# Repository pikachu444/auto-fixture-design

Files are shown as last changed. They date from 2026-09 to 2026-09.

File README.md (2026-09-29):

# Auto Fixture Design



시편 치수·물성, 시험기 구성, 프린터 출력 범위를 입력하면 **계산 → 제약 검사 → 실제 CAD 생성 → 파일 재검증 → 보고서**를 실행합니다. CadQuery/OpenCascade의 솔리드 모델을 STEP/STL/3MF로 출력합니다.

## 실행 결과 받기

1. [Actions](https://github.com/pikachu444/auto-fixture-design/actions/workflows/fixture-ci.yml)에서 최신 완료 실행을 엽니다.
2. **Artifacts → fixture-results-커밋SHA**를 다운로드합니다.
3. 압축을 풀고 **`suite/DESIGN_VERIFICATION.pdf`**를 열면 요구조건·계산·CAD 증거·차단 사례·수계산/해석·미검증 범위를 정리한 설계 검증 보고서를 볼 수 있습니다. `suite/REPORT.pdf`는 간단한 실행 요약입니다. `suite/index.html`에는 사례별 상세 보고서가 있고, 각 사례 폴더에는 CAD, HTML/Markdown 보고서, JSON, BOM이 있습니다.

`main`에 코드를 올리거나 PR을 만들 때 자동 실행하며 **Run workflow**로 수동 실행할 수도 있습니다. 저장 기간은 30일입니다. CI 성공은 계산·소프트웨어 회귀 검사 성공이며, 실물 제작 승인이 아닙니다.

## CAD 형상에서 치수를 선택해 파라미터 정의

화면의 **CAD 치수 정의** 탭은 편집 가능한 FreeCAD `.FCStd` 문서를 엽니다. 처음에는 사용자 파라미터가 없습니다. 실제 최종 솔리드를 마우스로 회전·확대하고 **면을 클릭**하면 기존 CAD 치수 중 해당 면이 변경되는 후보를 보여 줍니다. 후보 또는 전체 피처 트리에서 길이·반경이나 Sketcher 구동 치수를 선택하고 **이름과 허용 범위를 직접 지정**하면 그 정의가 `.FCStd` 원본에 저장됩니다. 이어서 정의한 값만 변경하고 원본을 재계산해 STEP/STL/3MF와 판정 보고서를 받습니다. 작성된 `.FCStd`를 다시 열어도 정의가 남습니다.

샘플 롤러 지지대에서는 `SupportBlock.Length`를 사용자가 `my_support_width`로 정의하여 폭 32→38 mm를 재생성합니다. 이어 `RollerCradle.Radius`와 `BoltBore1.Radius`를 선택할 수 있으며, 구멍 반경으로 외곽 여유가 2 mm 미만이 되면 CAD 출력을 차단합니다. 이 이름은 샘플 실행에서 사용자가 붙인 예시일 뿐, 화면에 고정된 입력 목록이 아닙니다. CI는 정의·재생성·원본 다시 열기·차단을 실제 FreeCAD로 실행합니다.

별도 **Sketcher 치수 예제**에서는 원형 스케치의 구동 반경을 선택해 `my_locator_radius`로 정의하고 4→6 mm로 변경한 출력물의 외경 12 mm를 확인합니다. 최종 형상에 영향을 주지 않는 피처 치수를 선택하면 등록을 거부합니다.

신뢰하는 `.FCStd` 문서를 직접 가져와 피처/스케치 치수를 정의할 수도 있습니다. 최종 출력할 솔리드가 표시되지 않으면 형상 트리에서 지정해야 합니다. 면을 클릭한 후보는 각 치수를 조금 변경해 FreeCAD를 재계산하고 해당 면의 변화 여부를 비교한 **제안**이므로 사용자가 설계 의도를 확인해야 합니다. 형상 면의 개수·순서가 바뀌는 변경에서는 후보를 제안하지 않습니다. 복잡한 문서(256면·64치수·5만 삼각형 초과)는 3D 선택을 생략하고 원래의 치수 트리를 사용합니다. FreeCAD GUI에서 새 Sketcher 구속을 추가한 후 저장한 문서를 가져오면 그 구동 치수가 후보가 됩니다. **피처 이력이 없는 STEP의 임의 면에서 구동 치수를 자동 복원하는 기능은 아닙니다.** 출력 강도·장비 장착은 별도 검증입니다.

로컬 실행에는 FreeCADCmd 1.1 계열을 설치하고 실행 파일 경로를 `FREECAD_CMD` 환경변수에 지정해야 합니다. Linux용 CI는 FreeCAD 1.1.4 AppImage를 SHA-256 확인 후 실행합니다. 이전 **소스 변수 변경** 탭은 CadQuery 파일에 미리 선언된 변수를 변경하는 기존 경로로 남겨 두었습니다.

## 구현한 사례

| 유형 | 실제 생성하는 부품 | 계산·검출 항목 |
|---|---|---|
| 3점 굽힘 | 슬롯 베이스·지지대, 금속 롤러 포함 조립체 | 4→8 mm 시편 변경, 간격 64→128 mm, 베이스 선택, 예상 하중·변위, 로드셀·공구·프린터 초과 |
| 필름 인장 | 시편 폭에 맞춘 벤치 정렬 트레이 | 물림 길이, 그립 폭, 예상 하중, 연신에 필요한 이동량 |
| 폼 압축 | 양 대각선의 탈착식 L자 위치 결정구 | 목표 압축률의 입력 응력 기반 하중, 압축판 범위, 가용 이동량 |
| 정적 굽힘 반경 | 반원형 반경 확인구 | 표면 변형률·최소 반경, 출력 크기 |

11개 시나리오: CAD 생성 후보 5개, 의도한 제약 위반 6개. 입력은 가상의 엔지니어링 사례이며 제조사 실험 데이터로 주장하지 않습니다. 설계 근거와 실제 사용 조건은 [ENGINEERING.md](docs/ENGINEERING.md)를 참고하세요.

### CAD 소스가 소유하는 파라미터

기존 11개 실험 규칙과 별도로 **CAD 모델 파라미터** 화면이 있습니다. `models/roller_support.py`, `models/film_tray.py`의 숫자 선언이 형상 치수의 원본이며 `FIXTURE_META`가 항목명·단위·허용 범위를 정의합니다. 프로그램은 CadQuery CQGI로 모델별 선언을 자동 발견해 입력 폼을 만들고, 바꾼 값으로 같은 CAD 소스를 다시 실행합니다. 모델 파일에 적힌 구멍 여유 등의 관계식이 실패하면 CAD를 내보내지 않습니다. 새로운 신뢰 가능한 CadQuery 모델을 `models/`에 추가하면 일반 실행 경로를 재사용하며 서버/화면에 그 형상을 하드코딩할 필요가 없습니다.

예를 들어 롤러 지지대의 `support_width_mm`를 32→38 mm로 바꾸면 재생성한 STEP의 폭도 38 mm가 됩니다. 독립 모델인 필름 트레이의 `specimen_width_mm`를 15→20 mm로 바꾸면 외곽 폭은 27.5→32.5 mm입니다. CI는 두 변형과 모델 내 관계식에 의한 거부를 `artifacts/models/`에 기록합니다.

**입력은 신뢰할 수 있는 로컬 Python CAD 파일로 제한합니다.** 임의 파일 업로드와 기존 STEP 파일의 파라미터 자동 복원은 제공하지 않습니다. STEP/STL/3MF는 내보내기 형상이며, 재편집 가능한 원본은 `.py` CAD 소스입니다. 이 두 신규 모델의 구조해석과 실제 장비 적합성은 아직 검증하지 않았습니다.

새 형상을 등록하려면 `models/새이름.py`에 `FIXTURE_META`와 파일 최상위의 숫자 할당을 같은 이름으로 작성하고, 그 숫자를 형상 작성 코드에 사용한 뒤 최종 출력 부품 하나를 `show_object(...)`로 지정합니다. 예를 들어 `body_width_mm = 12.0`과 메타데이터의 `body_width_mm` 항목을 선언하고 `cq.Workplane("XY").box(body_width_mm, 9, 7)`을 출력하면 화면에서 폭을 바꿀 수 있습니다. 파일을 저장하고 화면을 새로고침하면 모델 목록에 나타납니다. 이 경로는 신뢰할 수 있는 Python 코드만 실행하며 현재 단일 출력 솔리드와 mm 단위의 숫자 입력을 지원합니다. 새 모델의 물리적 검사 기준은 해당 CAD 소스의 관계식과 별도 엔지니어링 검토로 정의해야 합니다.

**현재 제작 승인 상태는 모두 UNKNOWN입니다.** 인장·압축 출력 보조구는 하중 시험 전에 제거합니다. 굽힘 지그의 출력물 강도·체결부·장비 어댑터는 검증 전입니다. 반경 확인구는 반복 폴딩 시험기가 아니며 피로수명을 예측하지 않습니다. 장비를 제어하지 않습니다.

### 구조해석 예비 검토

CI는 생성한 굽힘 지그의 **출력 지지대 STEP**을 Gmsh로 형상 경계에 맞춘 10절점 사면체 메시로 만들고 CalculiX에서 정적 선형 탄성 해석을 실행합니다. 작은 볼트 구멍 주변의 뒤집힌 곡면 요소를 피하려고 2차 절점은 직선 보간합니다. 따라서 곡면은 삼각형 면으로 근사되며 메시 세분화 검사가 필요합니다. 최대 요소 크기를 4→3→2 mm로 줄여 접촉부 수직 변위의 메시 민감도를 기록하며, 실제 FRD 응력장을 읽어 최대 평균 절점 von Mises 응력도 **진단값**으로 기록합니다. 원본 STEP·메시·해석 입력·FRD 결과와 `suite/structural_screen/result.json`을 보관합니다. 별도의 상용 라이선스는 필요 없습니다.

로컬에서도 Gmsh와 CalculiX `ccx`를 설치한 다음 실행할 수 있습니다.

```bash
python -m scripts.run_structural_screen --input examples/bend_8mm.json --material examples/printed_material_ASSUMED.json --output artifacts/structural-001
```

**이 결과로 지그 강도 합격 여부를 판정하지 않습니다.** 예제의 출력 방향별 탄성계수·전단계수는 측정값이 아닌 가정입니다. 입력 모델은 등방성 또는 직교이방성을 지원하며 CAD X/Y/Z와 출력 적층 방향의 대응을 명시해야 합니다. 지지대 바닥을 완전 고정하고 두 지지대가 설계 하중을 절반씩 받는다고 놓았습니다. 실제 베이스·체결부·비선형 롤러 접촉 및 출력 방향별 강도는 모델링하지 않았습니다. 지지대만 해석했으므로 전체 조립체 FEA나 출력물 실험을 대신하지 않습니다.

모든 사례 보고서에는 해당 시편의 하중·이동량·변형률에 대한 **병행 산술 대조**를 담습니다. 굽힘 해석 결과에는 지지대 총단면의 평균 압축응력 및 균일 축압축 변위도 FEA 접촉점 변위와 나란히 보여줍니다. 시편 수계산은 동일 이상화 식의 별도 구현 검사이며 실제 실험 검증은 아닙니다. 지지대 규모 비교는 구멍과 국부 접촉을 생략하므로 FEA와 일치해야 한다는 판정 기준으로 쓰지 않습니다.

## 로컬 프로그램 실행

Python 3.12 환경이 필요합니다.

```bash
python -m venv .venv
```

Windows PowerShell:

```powershell
.venv\Scripts\python.exe -m pip install -r requirements.txt
.venv\Scripts\python.exe -m fixturelab serve
```

macOS / Linux:

```bash
.venv/bin/python -m pip install -r requirements.txt
.venv/bin/python -m fixturelab serve
```

브라우저에서 `http://127.0.0.1:8765`를 엽니다. 사례를 선택하고 입력을 수정한 다음 **CAD 생성 및 검증 실행**을 누릅니다. 실제 생성 보고서를 표시하고 ZIP을 다운로드합니다. 로컬 접속만 허용하며 CAD 생성은 시간 제한이 있는 별도 프로세스에서 수행합니다.

화면에는 **기존 실험 예제**와 **CAD 모델 파라미터**가 따로 있습니다. 후자는 CAD 소스에서 항목을 읽어 폼을 만들고 STEP/STL/3MF를 재생성합니다. 형상은 정적 미리보기이며 회전 가능한 3D 편집기와 유한요소해석 실행 버튼은 없습니다. 기존 굽힘 조립체의 예비해석은 위 CLI 명령 또는 GitHub Actions에서 별도로 실행합니다. 자동으로 지그를 최적화하거나 대체 설계를 찾지는 않습니다.

## 명령줄 / 자동화

가상환경을 활성화한 터미널에서:

```bash
python -m fixturelab suite --output artifacts/run-001
python -m fixturelab generate --input examples/bend_8mm.json --output artifacts/custom-001
python -m fixturelab model --model roller_support --parameters examples/roller_width_38.json --output artifacts/model-001
```

결과가 섞이지 않도록 출력 디렉터리는 비어 있어야 합니다. 재실행에는 새 디렉터리 이름을 사용하세요. 단일 사례의 종료 코드: 0=계산 완료·검토 필요, 2=설계 제약 위반, 그 외=계산/입력 오류. suite는 기대 판정과 일치해야 0으로 끝납니다. 거부 사례를 무조건 오류로 취급하지 않습니다.

## 테스트

```bash
python -m pip install -r requirements-dev.txt
python -m pytest --junitxml=artifacts/unit-tests.xml
python -m fixturelab suite --output artifacts/test-suite
python -m playwright install chromium
python scripts/browser_smoke.py
```

설계 검증 PDF는 구조해석 결과까지 필요합니다. Gmsh와 CalculiX를 설치한 환경에서 suite 실행 후 다음을 추가로 실행합니다.

```bash
python -m scripts.run_structural_screen --input examples/bend_8mm.json --material examples/printed_material_ASSUMED.json --output artifacts/test-suite/structural_screen
python scripts/build_ci_report.py --suite artifacts/test-suite --output artifacts/test-suite/REPORT.pdf
python -m scripts.build_design_verification_report --suite artifacts/test-suite --output artifacts/test-suite/DESIGN_VERIFICATION.pdf
```

브라우저 검사는 Chromium에서 시편 폭을 변경하고 실제 CAD를 생성한 뒤 ZIP 내부 치수가 바뀌었는지 확인합니다. 이어서 이동량 부족 사례가 거부되는지 검사합니다. GitHub Actions는 브라우저 실행에 필요한 Linux 시스템 라이브러리도 설치합니다.
CAD 소스 파라미터 화면에서도 롤러 지지대 폭 변경과 관계식 위반 차단을 브라우저에서 검사합니다.

로컬 PDF 생성에는 한국어 TrueType 글꼴이 필요합니다. CI에서는 `fonts-nanum`을 설치해 PDF에 글꼴을 포함합니다. Windows에서는 시스템의 맑은 고딕을 사용합니다.

## 구성

- `fixturelab/`: 계산·파라메트릭 CAD·검증·보고서·로컬 웹 프로그램
- `models/`: 모델 내부에 숫자 파라미터·범위·형상 관계식을 가진 CadQuery 원본
- `examples/`: 편집 가능한 입력 JSON 및 기대 판정 목록
- `tests/`: 독립 보 공식, 경계, 오류 입력, 파일 재읽기 검사
- `.github/workflows/fixture-ci.yml`: 실제 실행·보고서·아티팩트 자동화
- `docs/ENGINEERING.md`: 식, 가정, 근거와 미구현 범위
- `docs/planning/`: 기존 상세 기획과 미실행 제품 인수 검사
- `legacy/`: 앞서 실행했던 첫 굽힘 데모와 당시 결과 보존

의존성 직접 버전을 고정하고 실제 설치된 전체 버전은 CI의 `resolved-environment.txt`에 기록합니다. 결과에는 입력 SHA-256, 실행 시간, 코드 커밋과 라이브러리 버전이 포함됩니다. G-code, 실제 출력, **지지대 외의 전체 조립체 FEA**, 피로시험 및 기존 CAD 파라미터 가져오기는 아직 구현하지 않았습니다.

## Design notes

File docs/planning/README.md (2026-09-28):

# 시험 지그 프로그램 개발 인계 패키지 1.1

## 읽는 순서
1. fixture_plan.md: 장비 선정, 기존 13개 시험 시나리오와 추가 6개 제작 시나리오, CAD·판정·화면·개발 명세.
2. equipment_profiles.json: 제조사 확인값과 미확인 항목. 실제 설치 장비의 인증 데이터가 아닙니다.
3. scenario_inputs.json: 개발용 입력. 실제 소재의 보증 물성이 아닙니다.
4. acceptance_tests.csv: 제품 구현 후 실행할 53개 수용시험. 현재 제품 테스트는 미실행입니다.
5. verify_planning_examples.py와 planning_calculation_results.json: 이번 기획의 수치 예제 검산과 실행 결과.

## 지금 완료된 것
상세 기획, 공개 장비 사양 조사, 개발 입력 정의, 수용시험 명세, 기획 예제 수치 검산.

## 아직 개발하지 않은 것
사용자 프로그램, CadQuery 기본 지그 템플릿과 선택적 FreeCAD 어댑터, 실제 CAD 자동 수정, 간섭·구조 해석, 실물 검증.

## 개발 시작 지시
fixture_plan.md 18절에 따라 공통 계산 엔진부터 구현하십시오. 제조사 미확인값을 가상값으로 덮어쓰지 말고, 필수 근거가 없는 검증은 UNKNOWN으로 두십시오. 네 시험 모두 대응하되 굽힘의 설계부터 3D 프린팅 제작 파일까지 전체 흐름을 먼저 완성하십시오. 기본 CAD 엔진은 CadQuery이고 FreeCAD는 기존 자산과 확인·편집에 사용합니다. 시편 치수와 목표 시험 조건은 고정하고 지그 변수만 허용 범위에서 수정하십시오. 제품 검증 시 acceptance_tests.csv의 실행 상태를 실제 결과로 갱신하십시오.

## 기획 검산 재실행
Python 표준 라이브러리만 필요합니다. 패키지 폴더에서 실행:
`python verify_planning_examples.py`

결과 파일은 기획 수치의 확인 기록이며 완성 프로그램 테스트 기록이 아닙니다.

## 3D 프린팅 확장
manufacturing_profiles.json, printing_scenarios.json, print_acceptance_tests.csv를 함께 읽으십시오. 추가 26개 수용시험을 포함해 전체 제품 수용시험은 79개입니다. 제품 수용시험은 아직 실행하지 않았습니다.

이번 개정은 자연어 변경 제안, CadQuery 원본, 출력 방향과 레시피, 프린터 프로파일, 3MF·G-code 구분, 출력물과 금속 부품 조립, 후가공·실물 검사를 정의합니다. 특정 프린터용 G-code와 실제 출력물은 아직 없습니다.

추가 기획 수치 검산은 `python verify_printing_examples.py`로 실행하고 printing_calculation_results.json에 저장합니다. 기존 검산 코드도 별도로 유지합니다.

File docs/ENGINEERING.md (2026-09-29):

# 엔지니어링 모델과 사용 범위

## 목적과 사례 선정

목표는 재제작을 유발하는 치수·장비 구성·출력 크기 불일치를 생성 전에 잡는 것입니다. 현재 프로그램은 새로 작성한 제한된 파라메트릭 템플릿을 사용합니다. 임의 CAD를 이해하거나 설계·강도·출력 가능성을 포괄적으로 보증하지 않습니다.

공식 제조사 자료에서 확인되는 요구를 바탕으로 사용 시나리오를 구성했습니다. 제조사의 기존 지그 도면을 복제하지 않았으며 연결부 호환성을 주장하지 않습니다.

- ZwickRoell [ISO 178 3점 굽힘](https://www.zwickroell.com/industries/plastics/thermoplastics-and-thermosetting-molding-materials/3-point-flexure-test-iso-178/): 지지 간격, 시편 치수와 변위 측정이 굽힘 평가에 영향을 줍니다. 본 예제는 간격/두께=16을 사용하지만 규격 전체 구현이 아닙니다.
- ZwickRoell [ISO 527-3 필름 인장](https://www.zwickroell.com/industries/plastics/thin-sheeting-and-plastic-films/tensile-properties-iso-527-3/): 얇은 필름의 정렬·물림과 큰 연신에 맞는 시험 공간이 중요하며 삽입 보조구가 실제로 사용됩니다. 본 출력물은 벤치 정렬 트레이입니다.
- ZwickRoell [압축시험](https://www.zwickroell.com/industries/materials-testing/compression-test/): 시편 크기·재질·하중에 맞는 압축판과 공구가 필요합니다. 본 출력물은 금속판 위에서 위치만 잡고 제거하는 보조구입니다.
- ZwickRoell [ProLine](https://www.zwickroell.com/products/static-materials-testing-machines/universal-testing-machines-for-static-applications/proline/): 기존 기획에서 선택한 Z010 TH 10 kN을 프레임 참조값으로 삼습니다. 예제의 500/2000 N 로드셀, 공구 용량, 40 mm 가용 이동량과 100 mm 압축판은 **개발 입력 가정**입니다. 실제 설치 구성으로 확인하지 않았습니다.

## 공통 단위와 판정

길이 mm, 힘 N, 응력·탄성계수 MPa=N/mm². 변형률은 백분율 숫자가 아니라 무차원 비율입니다. 예: 0.005=0.5%. 다른 단위 문자열과 알 수 없는 입력 키는 거부합니다.

`REVIEW_REQUIRED`: 계산된 제약에 실패가 없으나 미검증 항목이 있음.
`REJECTED`: 입력 치수·하중·이동량·출력 범위가 하나 이상의 제약을 위반함. CAD를 내보내지 않음.
`COMPUTATION_ERROR`: 생성된 CAD 검사가 실패함. CI도 실패함.
`production_release=UNKNOWN`: 실물 장비·출력재료·장착 검증을 하지 않았으므로 제작 승인을 내리지 않음.

로드셀이나 공구 정격이 빠지면 해당 항목은 UNKNOWN입니다. 프레임 정격으로 대체하거나 통과로 바꾸지 않습니다. 이미 명확한 실패가 있으면 UNKNOWN과 관계없이 REJECTED입니다.

## 3점 굽힘

직사각형 단면 b×h, 지지 간격 L, 중앙 집중 하중 F, 선형 Euler–Bernoulli 보를 가정합니다.

- I=bh³/12
- σ=3FL/(2bh²)
- δ=FL³/(48EI)
- ε=6hδ/L²
- 목표 변형률 하중: F=2bh²Eε/(3L)
- 명목 굽힘강도 하중: F_strength=2bh²σ_strength/(3L)
- 설계 요구 하중: F_design=load_factor×F_strength

목표 변형률의 하중과 강도 대응 하중을 혼동하지 않습니다. 강도까지 선형 탄성을 가정하지 않으며 명목 강도식은 하중 규모를 추정하는 데만 씁니다. 예제 1.25 배수는 물성/입력 가정이며 출력 지그의 강도 안전율을 대신하지 않습니다.

예제: b=10, h=8, L=128, E=2000, ε=0.005, σ_strength=80이면 목표 하중 33.333 N, 처짐 1.70667 mm, 명목 강도 하중 266.667 N, 설계 요구 하중 333.333 N입니다.

현재 템플릿: 지지 간격 40–160 mm, 시편 폭 ≤16 mm, 목표 변형률 ≤1%, 시편 끝 여유 각각 ≥8 mm. 베이스 길이 160 또는 220 mm, 폭 80 mm, 두께 12 mm, 지지대 32×40×26 mm, 롤러 Ø8×24 mm. 자동 선택은 두 후보 중 조건에 맞는 작은 후보를 고르는 것이며 형상 최적화가 아닙니다. 전단 변형, 접촉 압입, 시스템 컴플라이언스, 비선형 재료, 출력 이방성은 미포함입니다.

금속 볼트는 단순화 형상입니다. 나사산·너트·와셔·장비 장착 어댑터·롤러 축방향 보유 구조는 미완성입니다. 따라서 하중을 걸 수 있는 완성 지그로 취급하지 않습니다.

## 필름 인장 정렬구

- 하중 규모: F_design=b×t×σ_strength×load_factor
- 필요한 물림 길이: specimen_length ≥ grip_gap+2×engagement
- 이동량 근사: Δ=grip_gap×target_strain

15×0.2 mm 스트립, 강도 50 MPa이면 설계 요구 하중 187.5 N입니다. 자유 길이 100 mm의 80% 연신은 80 mm 이동량으로, 예제의 장착 후 가용 40 mm를 넘습니다.

출력 트레이는 홈 폭을 시편 폭+양쪽 공차로 바꿉니다. 금속 그립을 출력 트레이로 대체하지 않습니다. 트레이에서 정렬한 뒤 그립으로 옮기는 과정의 정렬 반복성은 실물 확인 대상입니다. 물림 압력·슬립·그립 파손·광학 변위계 범위는 아직 검증하지 않습니다. 비균일 변형에서는 자유 길이의 균일 변형률로 이동량을 예측하는 근사도 교체해야 합니다.

## 폼 압축 위치 결정구

- 시편 면적 A=b×l
- 사용자가 입력한 목표 압축률에서의 응력으로 F_design=A×σ_target×load_factor
- 이동량 Δ=h×ε_target

50×50×25 mm 폼, 40% 압축 시 응력 0.5 MPa라는 **가정**에서 하중 1562.5 N, 이동량 10 mm입니다. 폼 응력을 탄성계수에서 추측하거나 실제 측정 데이터처럼 표시하지 않습니다.

두 L자 결정구는 시편 밑에 깔리지 않습니다. 대각 방향으로 빼낸 후 금속판 사이에서 압축합니다. 시험 중 남겨두면 횡변형을 구속할 수 있으므로 반드시 제거합니다. 압축판에는 시편보다 각 방향 10 mm 큰 영역을 요구하는 개발 규칙을 적용하며 특정 규격 요구라고 주장하지 않습니다.

## 정적 굽힘 반경 확인구

균질 스트립의 중립축이 두께 중앙에 있고 순수 굽힘한다고 가정할 때:

- 중립축 반경 R_n=R_inner+t/2
- 표면 변형률 ε=t/(2R_inner+t)
- 최소 안쪽 반경 R_min=t(1/ε_allow−1)/2

t=0.3 mm, R_inner=20 mm이면 ε≈0.7444%. R=5 mm이면 ≈2.9126%로 예제 허용 1%를 넘습니다. 본 CAD는 반경을 실물로 확인할 수 있는 정적 형상입니다. CFRP/그래파이트 적층의 층간 슬립·비대칭 중립축, 150k회 피로와 박리, 액추에이터 스트로크/속도/주파수는 모델에 포함하지 않습니다. 반복 폴딩 지그는 후속 개발 대상입니다.

## CAD 및 출력 검사

OpenCascade 솔리드 유효성·양의 체적, STEP 재읽기의 솔리드 수·체적, STL/3MF의 밀폐성·면 방향·치수·체적, 초기 조립 상태의 교차 체적, CAD로 측정한 롤러 간격, CAD 바운딩 박스+브림의 베드 적합성을 실제 검사합니다. 단위와 파일 확장자만 확인하는 가짜 검사가 아닙니다.

굽힘 지그에서는 추가로 베이스의 최소·실제·최대 지지 간격에서 5.2 mm 볼트 여유 원통이 슬롯 전체 두께를 통과하는지, 조립된 볼트와 지지대 구멍의 간섭이 없는지, 롤러 지지점·시편·상부 노즈의 접촉 위치와 지지대 사이 간격을 CAD 형상에서 검사합니다. 슬롯은 일정 폭의 직선 구간이므로 끝점과 실제 위치 검사로 전 조절 구간을 검증합니다. 볼트의 축방향 고정력과 체결 후 하중 전달은 여전히 검증되지 않았습니다.

출력 범위 250×210×220 mm는 기존 기획의 MK4S 참조 범위입니다. 브림8+외곽여유1 mm를 양쪽에 추가합니다. 개별 부품의 고정 방향만 검사하며 플레이트 네스팅, 실제 베드 마스크, 슬라이싱·지지대·뒤틀림·출력 강도는 검사하지 않습니다. STL/3MF는 각 부품 바닥 Z=0에 배치합니다. 3MF는 형상 컨테이너이며 슬라이서 프로젝트가 아닙니다.

## 자동 실행의 의미

### 굽힘 출력 지지대의 구조해석 예비 검토

`scripts/run_structural_screen.py`는 실제 출력 지지대 CAD를 STEP으로 내보내고 Gmsh에서 10절점 사면체(C3D10)를 생성한 뒤 CalculiX로 선형 정적 해석합니다. 작은 구멍 주변에서 곡면 투영 2차 요소가 뒤집힐 수 있으므로 중간 절점은 직선 보간하고 삼각형 경계면의 형상 오차를 메시 세분화로 평가합니다. 모든 2차 요소의 4개 적분점에서 Jacobian을 검사합니다. 지지대 하단 완전 고정, 설계 요구 하중의 절반을 각 지지대의 롤러 받침 곡면 근처 절점에 균등 분배한다는 **단순화된 경계조건**을 사용합니다. 사면체의 꼭짓점으로 계산한 메시 체적과 CAD 체적을 비교하고, 접촉부 수직 변위를 두 메시 크기에서 비교합니다. 절점 변위는 CalculiX 실제 출력 파일에서 추출하며 솔버 실행 실패나 누락된 결과는 CI 실패입니다.

예제 `printed_material_ASSUMED.json`의 방향별 탄성계수·전단계수·포아송비는 근거가 없는 **소프트웨어 실행용 가정값**입니다. CalculiX의 직교이방성 탄성 입력을 사용하고 방향 1/2/3을 CAD X/Y/Z에 대응시킵니다. 실제 적층 방향과 시험편 측정 방향의 대응, 층간 강도, 기공·인필, 볼트 및 베이스, 접촉 비선형성, 실제 시험기 지지조건이 빠져 있습니다. 해석 변위는 경향 검토용이며 최댓값 응력의 메시 수렴이나 파손 안전율, 제작 승인을 주장하지 않습니다. 실제 설계 판정에는 장착 형상, 출력 공정별 물성·허용값, 접촉/체결 해석 및 시험 검증이 필요합니다.

동일 입력에서 별도 `fixturelab/handcheck.py`가 모든 11개 사례의 시편 산술을 다시 계산합니다. 굽힘은 단순보 단면계수와 중앙 집중하중으로 하중/처짐을, 인장은 단면적·강도 하중·연신량을, 압축은 가압 면적·입력 응력에 따른 하중·높이 변화를, 접힘은 중립축 가정의 표면 변형률·최소 반경을 대조합니다. 이는 **같은 이상화 식을 다른 코드로 계산해 옮겨 적는 오류를 잡는 검사**이지 새로운 물리 모델의 검증이 아닙니다. 지지대마다 `P=F_design/2`, 총단면 평균응력 `σ=P/A_gross`, 균일 축변위 `δ=P H/(E_z A_gross)`를 계산해 FEA 접촉부 변위와 병행 표시합니다. 지지대 국부 하중·구멍·롤러 받침을 생략하므로 이 수계산은 **규모 점검**이지 FEA 검증이나 안전율이 아닙니다.

GitHub Actions는 저장소에 구현된 코드를 실행·테스트하고 결과를 보관합니다. LLM이 무인으로 코드를 계속 작성하거나 검증 기준을 바꾸는 구조는 아닙니다. 개발은 Codex에서 이어가고, 각 변경이 CI의 동일 사례를 다시 통과하는지 확인하는 방식입니다.

### CAD 소스 정의 파라미터 (별도 경로)

`models/*.py`는 CadQuery 편집기에서 직접 고치는 CAD 원본입니다. 파일 최상위의 숫자 할당을 CQGI가 파라미터로 추출하고 같은 파일의 `FIXTURE_META`에 단위·표시명·허용 범위를 둡니다. `fixturelab/model_cad.py`는 등록된 로컬 모델만 읽어 화면·CLI 입력에 따라 다시 실행합니다. 모델 내부 관계식과 수치 범위가 맞으면 CAD를 내보낸 후 BREP, STEP 재읽기, STL/3MF 밀폐성·치수·체적을 검사합니다. 실패하면 REJECTED로 기록하고 CAD 파일은 생성하지 않습니다. 원본 소스 SHA-256과 원본 파일을 결과에 함께 남깁니다.

등록 모델은 롤러 지지대 단품과 필름 정렬 트레이 두 개입니다. 기존 11개 실험/장비 제약 사례와 독립된 CAD 소스 수정 사례이며, 굽힘 전체 조립체 해석을 롤러 지지대 단품의 새 파라미터에 자동 재연결하지 않았습니다. STEP 형상 자체에는 CadQuery 파라미터 이력이 없습니다. 사용자가 신뢰하는 CAD 스크립트만 `models/`에 추가해야 하며, 출력물 강도와 실제 장착 검증은 별도입니다.

### FreeCAD 원본의 치수 선택 및 정의

`fixturelab/freecad_worker.py`는 편집 가능한 `.FCStd`를 열어 `Part` 피처의 길이·거리 속성과 Sketcher의 구동 길이/반경/지름 구속을 수집합니다. 사용자는 후보 중 대상 치수를 선택하고 이름·범위를 지정합니다. 대상 객체의 내부 이름과 속성 또는 이름 붙인 구속을 문서 내부 `FixtureConfiguration.Definition`에 저장합니다. 새로운 피처 치수는 서버의 고정 입력 스키마를 수정하지 않아도 목록에 나타납니다. 이름 붙인 구속과 원본 문서는 함께 저장·재열기 검사합니다.

3D 뷰어에는 최종 FreeCAD BREP의 면별 삼각망을 전달합니다. 마우스 클릭은 화면의 깊이 버퍼에서 해당 CAD 면의 ID를 찾습니다. 등록 가능한 구동 치수를 각각 조금 변화시켜 `recompute()`하고 면의 종류·면적·무게중심·외곽 변화를 비교합니다. 면의 수가 변하면 해당 치수의 자동 매핑을 건너뜁니다. 이 결과는 단지 후보 제안이며 피처의 설계 의미를 증명하지 않습니다. 사용자는 전체 트리에서 직접 선택할 수도 있습니다. 복잡도 상한을 넘는 문서는 원래 트리와 정적 미리보기로 전환합니다.

값 변경은 FreeCAD에서 해당 피처 속성 또는 `SketchObject.setDatum`에 적용하고 `recompute()`한 뒤 단일 유효 솔리드를 STEP으로 내보냅니다. 기존 CAD 파일 검사기가 STEP 재읽기·STL/3MF의 밀폐성·치수·체적을 검사합니다. 샘플은 볼트 구멍의 실제 중심/반경과 블록 외곽으로 최소 2 mm 여유도 따로 검사합니다. 다른 문서의 설계 규칙을 이 샘플 규칙으로 대체하지 않습니다. 실제 시험기 장착·출력 재료 허용값·체결 해석은 미구현이며, 편집 이력이 없는 STEP만으로 파라메트릭 피처를 역생성하지 않습니다.

파라미터 등록 단계에서는 허용 범위 내에서 치수를 소폭 변경해 최종 솔리드의 체적·면적·외곽·무게중심이 바뀌는지 확인합니다. 관찰 가능한 형상 변화가 없으면 등록을 거부합니다. 이는 국부 형상 변화의 완전한 증명이 아니므로 변경 후에도 CAD 파일 검사를 다시 수행합니다. 별도 원형 Sketcher 예제에서 반경 구속을 사용자 이름으로 정의해 외경이 바뀌는 것도 실제 실행으로 검사합니다.

FreeCAD 공식 자료: [Sketcher 치수 구속 편집과 이름 지정](https://github.com/FreeCAD/FreeCAD-documentation/blob/main/wiki/Sketcher_Workbench.md), [Headless 실행과 스크립트](https://github.com/FreeCAD/FreeCAD-documentation/blob/main/wiki/Start_up_and_Configuration.md).

GitHub 공식: [워크플로 아티팩트](https://docs.github.com/en/actions/concepts/workflows-and-actions/workflow-artifacts), [수동 실행](https://docs.github.com/actions/managing-workflow-runs/manually-running-a-workflow). CAD 공식: [CadQuery 입출력](https://cadquery.readthedocs.io/en/latest/importexport.html), [Trimesh](https://trimesh.org/).

기존 기획의 79개 제품 인수 검사는 `docs/planning/`에 NOT_RUN 상태로 보존했습니다. 현재 11개 시나리오와 단위 검사는 제품 전체 완료를 의미하지 않습니다. 상용 CAD 라이선스 서버는 필요하지 않지만 각 오픈소스 의존성의 배포 조건은 별도로 따릅니다.

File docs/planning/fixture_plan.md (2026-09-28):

# 시험 지그 자동 설계와 사전 검증 프로그램 상세 기획

작성일 2026년 9월 28일 · 기획 버전 1.1 · 3D 프린팅 제작 과정 확장

## 1 목적과 개발 결정

소재 시편과 시험 조건을 입력하면 장비에서 시험할 수 있는지 먼저 판단하고, 지그 치수를 바꿔 해결할 수 있는 문제에는 수정 CAD를 만드는 프로그램을 개발한다. 지그 제작 후 발견하는 장착 불가, 하중 초과, 이동거리 부족, 지그 변형에 따른 측정 오류를 줄이는 것이 목적이다. 최종 산출물을 3D 프린팅 제작 파일, 금속 부품표, 조립·검사 정보까지 확장한다.

이번 개정에서는 자동 CAD 엔진을 CadQuery 중심으로 조정하고 FreeCAD는 기존 자산과 확인·편집 도구로 유지한다. 자연어 변경, 출력 재료·방향·레시피, 슬라이싱, 제작 후 확인은 20~27절에 상세히 정의한다.

| 결정 항목 | 채택안 | 이유 |
|---|---|---|
| 정적 시험 기준 장비 | ZwickRoell ProLine Z010 TH, 품목 059011, 10 kN | 인장·압축·굽힘에 대응하며 공개된 시험 공간·속도·연결부 사양이 구체적이다 |
| 반복 접힘의 동적 검토 장비 | Instron ElectroPuls E1000 | 동적 용량과 스트로크가 명시되어 있다. 접힘 지그 및 주파수별 운전 가능 여부는 추가 검증한다 |
| CAD 원본 | CadQuery 생성 Python과 parameters.json | 코드 기반 자동 생성·수정과 출력 파일 생성을 일관되게 관리한다 |
| CAD 확인과 기존 자산 | FreeCAD 및 선택적 FCStd 어댑터 | 형상 확인과 기존 파라메트릭 자산 편집을 지원한다 |
| 3D 프린팅 | PrusaSlicer CLI와 프린터별 프로파일 | 3MF와 실제 제작 조건을 묶어 슬라이싱과 제작 검사를 연결한다 |
| 사용자 프로그램 | Windows 우선 로컬 실행 프로그램, 브라우저 화면 | 회사 PC에서 자료를 외부로 보내지 않고 사용한다. 공개 사이트 배포는 필요 없다 |
| 3D 표시 | 실제 생성 CAD에서 만든 메시와 기구학 변환 | 형상과 결과가 연결되어야 하며, 단순 그림 위에 점만 표시하는 화면은 사용하지 않는다 |
| 첫 구현 순서 | 공통 엔진 → 굽힘 → 인장 → 압축 → 반복 접힘 → 챔버 공통 조건 | 네 시험을 모두 계획하되 검증하기 쉬운 순서로 개발한다 |
| 자동화의 범위 | 등록된 지그 계열 안에서 수정, 불가능하면 원인과 대안 제시 | 모든 CAD를 임의로 이해해 새 지그를 발명하는 기능은 범위에서 제외한다 |

이 문서는 개발 명세이며 완성 프로그램이나 제작 승인서가 아니다. 수치 시나리오는 검증 로직 개발용으로 정의한다. 제조사 사양, 프로젝트 가정, 계산값, 실측값을 데이터와 화면에서 구분한다.

성공 기준은 “CAD가 생성되었다”가 아니다. 입력 조건과 수정 이유를 추적할 수 있고, 알려진 실패 사례를 걸러내며, 계산과 형상 검증에 모두 통과한 설계안을 제시해야 한다.

## 2 장비 조사와 선정 근거

### 2.1 정적 장비 비교

| 항목 | Zwick ProLine Z010 TH | Instron 68TM-10 |
|---|---|---|
| 공칭 하중 | 10 kN | 10 kN |
| 대상 시험 | 인장·압축·굽힘 | 인장·압축·굽힘 |
| 이번 개발에서의 역할 | 기본 장비 프로파일 | 후속 교차 검증 프로파일 |
| 선정 판단 | 고신율 소재를 고려해 높은 시험 공간의 TH형을 선택 | 충분히 적합한 대안이나 1차 구현에서 두 제조사의 체결부를 동시에 구현하지 않는다 |

두 회사의 성능 우열을 단정한 선택이 아니다. 동일한 입력 구조로 다른 장비를 추가할 수 있도록 설계하고, 우선 하나의 정확한 모델과 형식에 집중한다. Z010이라는 이름만으로 ProLine과 AllroundLine의 사양을 혼용하지 않는다. [S1, S2]

### 2.2 기본 장비에 등록할 제조사 확인값

| 항목 | Zwick ProLine Z010 TH 값 | 해석 시 주의점 |
|---|---|---|
| 품목 번호 | 059011 | TN형 059010과 구별 |
| 최대 시험 하중 | 10,000 N | 장착한 로드셀·그립·어댑터는 별도 제한 |
| 시험 공간 높이 P | 1,450 mm | 부속품이 없는 공간. 시편의 허용 신장량이 아니다 |
| 크로스헤드 이동거리 | 1,380 mm | 조립 높이로 정해지는 가용 공간과 동시에 만족해야 한다 |
| 시험 공간 폭 | 440 mm | 챔버, 센서, 손잡이 등 국부 장애물은 별도 |
| 크로스헤드 시험 속도 | 0.0005~1,000 mm/min | 제조사 운전 조건을 함께 보관 |
| 복귀 속도 상한 | 1,500 mm/min | 시험 속도로 사용하지 않는다 |
| 연결 스터드 직경 | 20 mm | 끼워맞춤·횡핀·유효 길이·공차까지 확정된 것은 아니다 |
| 크로스헤드 부착 그립·공구 총질량 | 최대 20 kg | TH형의 공개 제한. 상부 부착품의 합산값에 적용 |

출처는 제조사 ProLine 표의 Z010 TH 열과 각주이다. 안전문 개방 시 속도 제한 등 운전 모드 조건도 프로파일에 보관한다. 제조사에서 설명하는 추가 하중 여유를 임의의 시험 용량 증대로 사용하지 않고 공칭 10 kN으로 계획한다. [S1]

정적 시험용 로드셀은 100 N, 1 kN, 10 kN의 세 용량군을 개발 목표로 둔다. 이는 선정 완료된 실제 재고 목록이 아니다. 제품 번호, 양방향 허용하중, 정확도 보증 범위, 교정 정보, 체결 호환성, 장착 질량을 확인한 부품만 실사용 후보에 올린다.

### 2.3 반복 접힘용 E1000 프로파일

| 항목 | 제조사 문서 확인값 |
|---|---|
| 동적 용량 | ±1,000 N |
| 정적 용량 | ±710 N |
| 총 스트로크 | 60 mm |
| 최대 개구 높이 | 액추에이터 중앙 위치에서 610 mm |
| 문서의 로드셀 | 베이스 장착 ±2 kN Dynacell |
| 하중 정확도 표현 | 지시값의 ±0.5% 또는 로드셀 용량의 ±0.005% 중 큰 값 |

출처 문서 표기는 ElectroPuls E1000_POD_EN_V9이다. 로드셀이 2 kN이어도 장비를 2 kN으로 사용하지 않는다. 동적 1 kN과 정적 710 N도 구분한다. [S3]

이 장비는 선형 액추에이터이므로 접힘에는 선형 변위를 회전으로 바꾸는 별도 기구가 필요하다. 60 mm 스트로크나 “100 Hz 이상”이라는 단일 문구로 특정 진폭·하중·질량에서의 연속 운전을 보증하지 않는다. 힘·진폭·주파수 운전 영역과 피로용 부속품의 정격을 확인하기 전에는 반복시험 적합 판정을 보류한다.

## 3 CAD와 라이선스 선택

**자동 형상 생성의 기본 엔진은 CadQuery로 정한다.** 3D 프린팅 제작까지 이어지는 코드 기반 자동화에 맞춰 1.0의 FreeCAD 중심 구성을 조정했다. Python 생성기와 parameters.json을 설계 원본으로 유지하고, STEP·STL·3MF·표시용 메시를 생성한다. FreeCAD는 형상 확인과 기존 FCStd 자산의 확인·편집 도구로 사용한다.

| 선택지 | 판단 |
|---|---|
| CadQuery | 기본 생성 엔진. Python 파라메트릭 모델·조립·STEP와 3MF 출력에 사용 |
| build123d | 대안 엔진. 동일 템플릿으로 실제 이점이 확인되는 경우 어댑터 교체 검토 |
| FreeCAD | 확인·편집 및 기존 FCStd 템플릿 지원. 기본 엔진과 부품 원본을 중복 관리하지 않음 |
| 상용 CAD | 기존 사내 자산을 연동하는 후속 선택지. 초기 실행에 필수로 두지 않음 |

CadQuery와 build123d는 Apache 2.0 기반이고 FreeCAD는 기업 사용이 가능한 오픈소스 CAD다. 실행 환경 배포 시 각 도구와 의존성의 라이선스 조건을 관리한다. “아무 제한도 없다”는 의미는 아니다. [S4~S6, S13]

파라미터의 원본은 parameters.json이고 CadQuery 생성기는 허용 범위와 설계 종속성을 구현한다. 사용자가 코드를 변경하면 새 템플릿 버전을 만들고 계산·형상·제조 검증을 다시 수행한다. 기존 FreeCAD 자산은 cad_backend=freecad인 별도 템플릿으로 지원할 수 있다.

STEP는 교환용 형상이며 원래의 피처 이력·수식·설계 의도를 일반적으로 보존하지 않는다. CadQuery STEP를 FreeCAD로 열면 형상을 확인할 수 있지만 CadQuery의 파라메트릭 이력이 복원되지는 않는다. 다른 CAD의 STEP만 받고 원본 파라미터를 자동 복원한다고 약속하지 않는다. [S12]

제조사 CAD에는 사용 조건이 있을 수 있으므로 배포 패키지에 무조건 포함하지 않는다. 공개 치수에서 만든 단순 공간 모델과 실제 체결부 형상을 구분한다. 도구 비교와 출력 파이프라인은 20~27절에서 구체화한다. [S2]

## 4 사용 흐름과 화면

사용자는 시험을 고르고 시편 정보를 넣은 뒤, 보유 장비 구성을 선택한다. 프로그램은 현재 지그의 문제를 보여주고 수정안을 계산한다. 사용자가 수정안을 선택하면 같은 검증을 다시 수행한 CAD와 보고서를 저장한다. 제작 화면에서 출력 방향·프린터·재료·부품표를 확인하고 슬라이싱과 제작 후 검사로 이어간다.

| 화면 | 입력과 기능 | 반드시 보일 결과 |
|---|---|---|
| 시험 만들기 | 인장·압축·3점 굽힘·반복 접힘 선택, 프로젝트 불러오기 | 시험 목적, 비교 기준, 사용하는 단위 |
| 시편과 조건 | 치수·물성 범위, 온도, 속도, 목표 변형·횟수 | 필수 누락값, 예상 범위, 출처 구분 |
| 장비와 지그 | 본체 → 로드셀 → 어댑터 → 지그의 실제 조립 구성 | 전체 제한을 결정하는 부품, 조립 높이·질량 |
| 검증 결과 | 계산 결과, 제약별 판정, 근거 펼치기 | 현재값 / 요구값 / 허용값 / 차이 / 해결 방법 |
| 수정안 비교 | 원안과 후보를 나란히 확인 | 변경 치수, 교체 부품, 남은 문제, 신규 제작 부품 |
| 3D 동작 확인 | 회전·확대·분해, 변위 또는 각도 슬라이더 | 실제 CAD 부품, 이동 궤적, 충돌 위치, 센서 위치 |
| 결과 내보내기 | 원본 CAD·STEP·검토 보고서·입력 묶음 | 버전과 검증 범위, 누락 항목 |

기본 화면에서는 시험에 필요한 항목만 보인다. 물성 근거, 안전 여유, 접촉 가정, 세부 공차는 확장 영역에서 보여준다. 값 하나를 바꾸면 이전 결과에는 “입력 변경으로 재검증 필요” 표시를 붙인다.

3D 애니메이션은 기구학 표시인지, 해석 결과인지 명확히 표시한다. 솔버 없이 시편을 시각적으로 휘게 만든 그림을 응력 해석 결과처럼 표시하지 않는다. 지그·시편·로드셀은 별도 선택 가능 객체이며 객체를 누르면 연결된 검증 항목이 열린다.

## 5 공통 판정 규칙

### 5.1 판정 상태

| 상태 | 정의 | 예시 |
|---|---|---|
| PASS 조건 내 적합 | 해당 검증에 필요한 데이터가 있고 기준을 만족 | 확인된 최대 하중 이내 |
| FAIL 부적합 | 확인된 한계를 위반 | 1 kN 로드셀에 설계 하중 2.5 kN |
| UNKNOWN 판정 보류 | 필수 사양·모델·실측 근거가 없음 | 체결 핀 허용하중 미등록 |
| WARNING 확인 권고 | 판정은 가능하지만 여유나 모델 적용성이 제한적 | 허용치에 가까운 공간 여유 |

FAIL이 하나라도 있으면 현재 구성은 부적합이다. FAIL이 없어도 필수 UNKNOWN이 있으면 종합 적합을 주지 않는다. 계산 검증, 형상 검증, 구조 검증, 실물 검증은 별도 상태로 저장한다. 시뮬레이션 예제의 PASS는 실제 장비 적합과 다르다.

### 5.2 모든 시험의 필수 검사

1. 단위와 입력 유효성: mm와 m, N와 kN, Pa와 MPa, %와 비율 혼동을 차단한다. 범위 역전·음수 치수·NaN도 거부한다.
2. 적용 가능성: 선택한 계산식이 재료·변형 범위·시험 방법에 적합한지 먼저 판단한다.
3. 하중 경로: 본체, 로드셀, 그립, 핀, 볼트, 어댑터, 지그의 방향별 허용치를 각각 비교한다. 자중과 편심, 동적 관성은 해당 부품에 실제로 작용하는 만큼 포함한다.
4. 공간과 이동: 초기 조립과 시험 종료 상태뿐 아니라 중간 경로에서 공간, 이동거리, 센서·챔버 간섭을 검사한다.
5. 측정 품질: 관심 구간의 하중·변위가 센서 보증 범위에 있는지, 지그·프레임 변형이 측정에 섞이는지 검사한다.
6. 형상과 구조: CAD 재생성, 솔리드 유효성, 실제 반영 치수, 연결 관계, 강도·강성 검증 범위를 확인한다.
7. 제작 가능성: 선택한 가공 방식의 최소 두께, 구멍 간격, 공구 접근, 조립 순서, 표준 부품 크기를 확인한다.

### 5.3 변경 권한

자동 변경 가능: 등록 범위 안의 지그 판 두께, 베이스 길이, 지지대 위치, 물림 길이, 교체형 인서트, 어댑터 길이, 재고 부품 선택.

고정 조건: 시험 규격, 목표 접힘 반경·각도·횟수, 시편 단면·적층·길이, 비교 시험의 경계조건. 고정 조건을 바꿔야만 해결되면 별도 대안으로 표시하고 원 시험의 성공으로 간주하지 않는다.

개발 예제의 하중 설계 계수는 1.25로 둔다. 이것은 규격의 보편적 안전율이 아니라 계획용 여유이다. 재료 물성의 상한과 별도로 적용하며, 장비 제조사가 지정한 한계는 늘리지 않는다. 부품 강도에 적용할 안전율·피로 계수는 검토 정책에서 따로 정한다.

## 6 인장시험 시나리오

### T1 강한 플라스틱으로 바뀌어 로드셀과 연결부가 부족한 경우

개발 입력: 시험부 폭 10 mm, 두께 2 mm, 예상 공칭 인장강도 60~100 MPa. 예상 최대 하중 범위는 1.2~2.0 kN이고 설계 하중은 상한의 1.25배인 2.5 kN이다.

현재 구성은 1 kN 로드셀, 2 kN 연결 어댑터를 가정한다. 10 kN 본체가 있어도 두 부품 모두 부적합이다. 프로그램은 확인된 호환 부품 중 적합한 로드셀·어댑터를 먼저 찾고, 연결부 두께·핀 지름 변경이 허용된 템플릿에서는 구조 검토가 가능한 후보를 만든다. 센서 용량은 CAD 치수 변경으로 해결하지 않는다.

출력 예: “로드셀 1,000 N < 설계 하중 2,500 N. 어댑터 2,000 N < 2,500 N. 본체는 용량 이내. 두 부품 교체 후 체결·공간 재검증 필요.”

인장 최대 하중은 공칭강도 × 초기 단면적으로 산정한다. 항복강도만 입력되면 파단까지의 최대 하중을 알 수 없으므로 파단시험 적합을 확정하지 않는다. 진응력은 초기 면적과 직접 곱하지 않는다.

### T2 고무가 길게 늘어나 종료 전에 공간이 부족한 경우

개발 입력: 평행부의 균일 스트립, 폭 4 mm, 두께 2 mm, 초기 그립 간 자유 길이 100 mm, 목표 공칭 신장률 500%, 예상 강도 상한 15 MPa. 시편 신장량은 500 mm, 시편 힘은 약 120 N, 설계 하중은 150 N이다.

개발 조립 가정: 시편을 제외한 로드셀·그립·긴 연장봉 합산 높이 800 mm, 끝단 여유 100 mm. Z010 TH의 1,450 mm 공간에서 쓸 수 있는 추가 신장량은 450 mm이므로 50 mm 부족하다. 긴 연장봉을 줄여 합산 높이 650 mm로 만들면 가용 신장량은 600 mm가 된다. 크로스헤드 위치와 센서 추적 범위도 별도 확인한다.

자동 변경: 연장봉·어댑터 길이와 설치 높이. 변경 금지: 물성시험의 목표 신장률이나 시편 규정 치수. 덤벨 시편에서는 표점 길이 × 신장률을 그립 이동량과 동일하게 쓰지 않고, 어깨부 변형을 포함한 추정 또는 실측 변위 이력을 사용한다.

### T3 얇은 필름의 미끄러짐과 저하중 측정 문제

개발 입력: 폭 10 mm, 두께 0.05 mm, 강도 상한 80 MPa. 예상 최대 힘 40 N, 설계 하중 50 N이다. 파단 하중만 보면 큰 로드셀에도 충분하지만, 탄성구간의 관심 하중이 0.1 N이면 보증 범위가 이를 포함해야 한다.

로드셀은 용량보다 교정·정확도 범위를 먼저 비교한다. 예제용 큰 로드셀의 보증 하한 1 N, 작은 로드셀의 보증 하한 0.02 N을 별도 가상 데이터로 둔다. 이 값은 실제 Zwick 제품 사양이 아니다.

그립은 양면 접촉압, 마찰계수의 범위, 물림 길이, 표면 종류를 입력한다. 단순 마찰 모델은 미끄러짐의 1차 평가에만 쓰며, 패드 압축·필름 찢어짐의 한계가 없으면 UNKNOWN으로 둔다. 자동 변경은 물림 길이·패드 두께·모서리 반경이며, 최종 확인은 소량 시편의 미끄러짐·물림부 파손 시험이다. ISO 527-3과 ASTM D882는 동등한 규칙 묶음으로 취급하지 않는다. [S7]

## 7 압축시험 시나리오

### C1 발포재 크기가 커져 하중과 압축판 크기가 달라진 경우

개발 입력: 50 × 50 × 25 mm 발포재, 목표 압축률 50%, 해당 변형에서 공칭 압축응력 상한 0.2 MPa. 예상 힘은 500 N, 설계 하중 625 N, 시편 압축 변위는 12.5 mm이다.

자동 변경: 평판 폭·길이·두께, 센서 브래킷 높이. 70 × 70 mm 평판을 첫 후보로 두되, 이것은 시험 규격을 확정한 값이 아니다. 시편의 횡방향 팽창과 끝단 마찰 조건을 확인한다. 반력 지지 위치와 판 휨을 검토하고, 압축 종료 전에 지그가 닿는지 검사한다.

발포재에 선형 탄성률 하나만 주고 50% 압축력을 계산하지 않는다. 압축 곡선이나 목표 압축률에서의 응력 범위가 필요하다. 발포재와 단단한 플라스틱은 다른 시험법 프로파일을 사용한다. [S8]

### C2 단단한 시편보다 지그 변형이 커서 탄성률이 틀어지는 경우

개발 입력: 단면 10 × 10 mm, 높이 10 mm, 탄성률 3,000 MPa, 선형 범위 내 목표 변형률 2%라는 가정. 힘은 6,000 N, 시편 변형은 0.2 mm, 설계 하중은 7,500 N이다.

지그 축방향 강성을 20,000 N/mm로 가정하면 지그만 0.3 mm 변형한다. 크로스헤드에서 0.5 mm를 모두 시편 변형으로 해석하면 겉보기 탄성률은 1,200 MPa가 된다. 이 계산은 프레임·로드셀의 추가 변형을 제외한 설명 예제다.

프로그램은 지그 강성 증대안과 시편 직접 변위 측정안을 나란히 보여준다. 지그 변형을 시편 변형의 5% 이내로 제한한다는 개발 목표라면 필요한 지그 강성은 600,000 N/mm 이상이다. 판 두께만 조금 늘려 해결된다고 처리하지 않는다. 직접 변위계를 쓰더라도 평행도·접촉면·좌굴과 하중 전달 문제는 별도 검토한다. [S9]

### C3 지그를 아무리 바꿔도 본체 용량이 부족한 경우

개발 입력: 단면 20 × 20 mm, 목표 공칭 압축응력 40 MPa. 힘 16 kN, 설계 하중 20 kN으로 10 kN 본체를 초과한다.

결과는 “현 장비에서 불가”다. 시편 면적을 몰래 줄이지 않는다. 더 큰 장비로 전환하거나, 시험법이 허용하는 시편 변경을 별도 검토안으로 제시한다. 이 실패 시나리오는 프로그램이 무조건 CAD 수정안을 내지 않는지 확인하는 핵심 테스트다.

## 8 3점 굽힘 시나리오

### B1 기본 플라스틱 시편의 굽힘 지그 생성

개발 입력: 폭 10 mm, 두께 4 mm, 길이 80 mm, 지지 간격 64 mm, 탄성률 2,000 MPa. 소변형 선형보 가정에서 표면 변형률 0.5%에 대응하는 힘은 약 16.667 N, 중앙 처짐은 약 0.8533 mm이다.

공칭 굽힘강도 80 MPa에서의 하중 환산값은 약 133.333 N이고 1.25배 설계 하중은 약 166.667 N이다. 선형 탄성률로 파단 처짐까지 외삽하지 않는다. 목표 처짐은 시험 방법 또는 실제 곡선에서 별도로 입력한다.

지그 구성: 베이스, 좌우 위치 조절 지지대, 교체형 지지 롤러, 중앙 압자, 정렬 스토퍼, 시편 아래의 독립 변위 센서 브래킷. 지지대는 중심을 유지하며 대칭 이동한다. 롤러·압자 반경은 승인된 시험법 프로파일에서 정하고, 하중을 낮추기 위한 자유 최적화 변수로 쓰지 않는다. [S10]

### B2 시편 두께 증가로 지지 간격이 기존 조절 범위를 벗어난 경우

개발 입력: 폭 10 mm, 두께 8 mm, 길이 200 mm. 개발 규칙으로 지지 간격/두께 비 16을 지정하면 지지 간격 128 mm가 필요하다. 이 비율은 모든 재료·규격에 공통 적용하지 않는다.

기존 지그의 최대 지지 간격을 100 mm로 가정한다. 프로그램은 128 mm까지 지지대를 이동시키는 동시에 베이스 길이·가이드 유효 길이·볼트 위치를 바꾼다. 220 mm 베이스와 최대 간격 160 mm를 초기 후보로 두고, 실제 CAD와 구조 검증 후 채택한다.

동일 0.5% 표면 변형률에서 약 33.333 N, 처짐 1.7067 mm이며, 굽힘강도 80 MPa 기준 하중은 약 266.667 N이다. 단순히 “두께 두 배이므로 힘 여덟 배”로 계산하지 않는다. 지지 간격과 목표 변형 조건도 동시에 달라졌기 때문이다.

시편 길이를 80 mm로 유지한 입력에서는 128 mm 지지 간격을 수용할 수 없다. 지그 확대만으로 해결되었다고 판정하지 않는다.

### B3 적층 복합재와 전단 변형이 중요한 경우

입력에 적층 방향, 각 층 두께, 방향별 탄성률과 전단 계수, 계면 조건을 추가한다. 등방성 탄성률 하나와 두께만으로 모든 적층재를 판정하지 않는다. 필요하면 적층판 강성 또는 전단 변형을 포함한 보 모델, 접촉 해석으로 넘긴다.

초기 버전은 CAD 형상·공간·입력 하중 기반 용량 검사를 지원한다. 신뢰할 수 있는 하중 곡선이나 해석 결과가 없으면 하중 예측과 박리·파손 판단은 UNKNOWN으로 둔다. 적층 손상 수명 예측을 지그 자동 치수화 기능과 혼동하지 않는다.

## 9 반복 접힘 시나리오

### F1 접힘 반경은 같아도 두꺼운 소재에서 요구 변형이 증가하는 경우

단층 필름의 개발 입력: 두께 0.2 mm, 폭 20 mm, 안쪽 반경 2 mm. 중립면이 두께 중앙에 있고 원호로 순수 굽힘한다는 가정에서 중립면 반경은 2.1 mm, 표면 변형률은 약 4.762%다.

반경을 5 mm로 바꾸면 약 1.961%로 낮아지지만, 원 시험의 목표 반경이 2 mm이면 이를 자동 해결안으로 적용하지 않는다. 프로그램은 “시편 요구 변형이 지정한 재료 모델의 검증 범위를 초과한다”를 표시하고 하중 예측의 신뢰도를 낮춘다.

기구 구성: 좌우 회전 클램프, 반경 인서트, 시편 길이 변화를 흡수하는 슬라이드 또는 부동 그립, 대칭 구동부, 회전각 센서, 가이드 베어링. 각도만 맞고 시편에 불필요한 인장력이 생기는 구조를 허용하지 않는다. 시편 중심선 궤적·그립 사이 길이·접촉점 이동을 함께 검사한다.

적층재에서는 중립면 위치, 층간 미끄러짐과 박리를 고려해야 한다. 단층 계산을 CFRP와 슬립 시트 적층재의 손상 판단에 그대로 쓰지 않는다.

### F2 15만 회 반복 접힘의 속도와 관성 검토

개발 목표: 평탄 상태 0°에서 접힘 180°까지 왕복, 초당 2회, 총 150,000회. 정지 시간을 제외한 순수 운전 시간은 약 20.833시간이다.

기구학 검증용 모델은 피치 반경 12 mm인 랙·피니언과 좌우 반대 회전 기어를 사용한다. 각 클램프가 전체 접힘각의 절반씩 회전한다고 가정하면 전체 각도 θ에 대해 랙 이동 x = r × θ / 2가 된다. θ는 라디안이다. 전체 선형 스트로크는 약 18.850 mm다. 실제 베어링·백래시·가이드·그립 궤적을 설계하기 전의 이상 기구학 모델이다.

2 Hz 정현 운동에서 선형 진폭은 약 9.425 mm, 최대 속도는 118.435 mm/s, 즉 7,106.1 mm/min이다. 이는 Z010 TH의 시험 속도 1,000 mm/min보다 크다. 정적 장비에 지그만 달아 목표 시험이 된다고 판정해서는 안 된다.

E1000의 60 mm 총 스트로크 안에는 들어가지만 이것만으로 적합은 아니다. 최대 가속도 약 1.488 m/s², 움직이는 질량 0.5 kg을 가정한 선형 관성력 약 0.744 N 외에 회전 관성·마찰·시편 저항·부품 자중을 포함해야 한다. 시편이 약하면 관성력도 측정값을 크게 오염시킬 수 있다.

일반 기구의 액추에이터 힘은 순간 기구비에 의해 달라진다. 각도에 대한 변위 미분이 0에 가까워지는 사점, 끝단 충돌, 허용 편심, 베어링 수명, 풀림, 피로를 검사한다. 본 예의 이상 랙 구동은 일정 기구비를 가지지만 시편 굽힘 반경 유지와 길이 보상까지 자동 보장하지 않는다.

### F3 접힘 힘이 작아 센서의 오차가 지배하는 경우

E1000 문서의 2 kN 로드셀과 정확도 식을 적용하면 절대오차 하한은 0.1 N이다. 시편 신호가 2 N인 예에서는 지시값 0.5%인 0.01 N보다 0.1 N이 크므로 상대오차는 5%다. 목표 정확도가 1%라면 이 구성의 측정 품질은 부적합이다. [S3]

대안은 제조사가 허용한 더 적합한 측정 구성, 별도 센서, 기구비 변경이다. 기구비를 바꾸면 힘뿐 아니라 스트로크·속도·관성·백래시도 다시 검토한다. 저하중 접힘을 위해 동적 장비 이름만 바꾸면 해결된다고 처리하지 않는다.

초기 반복 접힘 기능의 완료 범위는 기구학·공간·하중 경로·측정 범위 검토와 CAD 생성이다. 15만 회에서의 시편 균열·계면 박리 수명은 별도 재료·피로 모델 및 실험 검증이 필요한 후속 기능이다.

## 10 챔버와 환경 조건 공통 시나리오

### H1 상온에서 맞는 지그가 온도 챔버에서 충돌하는 경우

개발 가정은 유효 내부 폭 200 mm, 깊이 200 mm, 높이 300 mm인 가상 챔버다. 제조사 제품의 실제 사양으로 등록하지 않는다. 폭 210 mm 지그는 정지 상태부터 들어가지 않는다. 폭을 줄였어도 회전하는 손잡이, 이동하는 압자, 센서 암, 케이블이 중간 위치에서 충돌할 수 있다.

일정 여유를 가진 챔버 공간 모델과 지그의 운동 궤적을 비교한다. 고온·저온에서는 지그 재료 강도, 치수 변화, 윤활·패드·접착제, 센서 정격, 열전달과 온도 안정화를 추가 검토한다. 온도별 물성 정보가 없으면 상온 값을 자동 적용하지 않는다.

E1000에 일반적인 챔버를 조합할 수 있다고 가정하지 않는다. 제조사의 ElectroPuls 액세서리 안내에는 E1000이 제외되는 챔버도 있으므로 장비별 호환 품목을 확인해야 한다. [S11]

## 11 계산 모델과 적용 한계

기본 내부 단위는 N, mm, s, MPa, rad, kg로 통일한다. 질량에서 관성력을 구할 때 가속도 mm/s²를 m/s²로 변환한다. CAD 길이 단위는 mm다. 외부 입력은 단위를 명시한 뒤 변환한다.

| 계산 | 식 또는 처리 | 적용 한계 |
|---|---|---|
| 인장 최대 하중 | F = 공칭강도 × 초기 단면적 | 강도 범위·온도·속도 조건 필요 |
| 균일 스트립 신장 | ΔL = 초기 자유 길이 × 공칭 신장률 | 덤벨·그립 미끄러짐에는 직접 적용 금지 |
| 압축 하중 | F = 공칭 압축응력 × 초기 단면적 | 진응력 또는 횡팽창이 큰 경우 면적 정의를 구분 |
| 선형 압축 | F = E × A × δ / L | 작은 변형의 검증된 선형 구간만 |
| 3점 굽힘 응력 | σ = 3 F L / (2 b h²) | 단순 지지, 중앙 하중, 적합한 보 모델 |
| 3점 굽힘 처짐 | δ = F L³ / (4 E b h³) | 소변형·선형 탄성·전단 영향이 작은 구간 |
| 굽힘 표면 변형률 | ε = 6 h δ / L² | 같은 보 모델의 적용 조건 |
| 단층 순수 굽힘 | ε ≈ h / (2 R중립면) | 중립면·막변형·층간 미끄러짐 가정 필요 |
| 직렬 탄성 컴플라이언스 | C전체 = C시편 + C지그 + C로드셀 + C프레임 | 접촉·유격·미끄러짐은 별도 |
| 정현 운동 | vmax = 2πfA, amax = (2πf)²A | A는 편진폭. 왕복 스트로크와 구분 |
| 운전 시간 | 시간 = 사이클 수 / 주파수 | 휴지·점검·가감속 시간 별도 |
| 일반 기구 힘 | F = Mθ / (dx/dθ) | θ에 대응하는 일반화 모멘트 정의, 마찰·관성 추가 |

표의 식은 개발 계산 모델의 정의다. 시험 규격 전체를 구현한 것으로 취급하지 않는다. 규격 프로파일에는 문서명·판·적용 소재·시편 조건·허용 변경·검토자를 저장한다. 공개 제조사 해설로 후보 규칙을 만들 수 있지만, 규격 적합 표시를 제공하기 전에는 실제 적용 판의 정식 문서와 대조한다.

체결부 강도는 단면적만으로 승인하지 않는다. 핀 전단·베어링 압력·순단면·볼트 인장과 전단·예압·굽힘·응력집중을 필요한 수준으로 평가한다. 적용할 구조 모델이 등록되지 않은 지그는 CAD만 생성 가능하고 구조 검증은 UNKNOWN이다.

## 12 자동 수정과 후보 선택 알고리즘

1. 입력, 장비 구성, 규칙, CAD 템플릿 버전을 고정하고 해시를 만든다.
2. 현재 구성을 평가한다. 누락 필수 데이터와 확정 위반을 분리한다.
3. 위반마다 수정 가능한 변수를 연결한다. 하중 초과를 베이스 길이 변경으로 해결하는 식의 무관한 조정을 금지한다.
4. 기존 부품의 위치 조절 → 재고 부품 교체 → 신규 부품 최소 제작 순서로 후보를 만든다.
5. 물성의 상·하한과 치수 공차를 사용해 후보를 검사한다. 입력이 충분하지 않으면 “강건한 설계”라고 표현하지 않는다.
6. 계산식으로 빠르게 탈락시킨 후 남은 후보만 CAD로 생성한다.
7. CAD 유효성·실제 치수·전 경로 간섭·질량·연결을 검사한다. 필요한 구조 검증을 수행하거나 UNKNOWN으로 남긴다.
8. 모든 고정 조건을 유지한 후보 중 신규 제작 부품 수, 변경량, 공간 여유, 검증된 성능으로 순위를 정한다. 미확인 가공비를 숫자로 만들어 비용 최적화했다고 표시하지 않는다.
9. 해결 후보가 없으면 위반 조건과 변경 가능한 대안을 출력한다. 탐색 횟수 소진과 물리적 불가능을 구분한다.

초기에는 등록된 이산 부품과 제한된 치수 범위를 열거하는 결정적 알고리즘을 사용한다. 근거가 약한 다목적 최적화와 LLM 판단을 핵심 판정에 넣지 않는다. 같은 입력과 같은 버전이면 수치와 판정이 재현되어야 한다.

## 13 CAD 템플릿 상세

| 템플릿 | 부품 구성 | 주요 자동 변경값 | 고정 또는 제한값 |
|---|---|---|---|
| T 인장 | 상하 그립, 인서트, 어댑터, 연결 핀, 시편 | 물림 길이, 패드 두께, 어댑터 길이 | 시험부 치수, 하중축, 제조사 체결 규격 |
| C 압축 | 상하 평판, 지지 블록, 정렬부, 변위계 브래킷 | 평판 폭·길이·두께, 브래킷 높이 | 시편 단면, 목표 압축량, 평행도 요구 |
| B 굽힘 | 베이스, 지지대, 롤러, 중앙 압자, 위치 스토퍼 | 지지 간격, 베이스 길이·두께, 볼트 위치 | 시험법의 롤러 반경, 압자 중심, 규정 지지 간격 |
| F 접힘 | 좌우 클램프, 기어·랙, 회전축, 인서트, 슬라이드, 센서 | 클램프 폭, 부동 길이, 가이드 길이, 축 지지 간격 | 목표 반경·각도, 하중축, 규정 기구 운동 |

모든 치수에 이름, 단위, 최소·최대·증분, 역할, 종속식, 고정 여부, 검증 방법을 부여한다. 형상 참조는 임의 Face1·Edge2 번호에 의존하지 않고 기준 좌표계·기준면·이름 있는 객체를 사용한다.

연결부에는 제조사 도면의 실제 길이·공차·핀 위치를 등록해야 한다. 직경 20 mm만 확인된 상태에서는 원통형 참고 모델을 만들 수 있지만 실제 제작 가능한 어댑터로 내보내지 않는다. CAD의 마지막 정상 형상을 보존하고 재생성 실패 파일을 정상 결과처럼 표시하지 않는다.

기본 운동 검증은 일정 간격의 위치를 확인하고 간격이 좁아지는 구간을 적응적으로 세분한다. 단순 위치 샘플만으로 모든 간섭이 없다고 보증하지 않는다. 중요 구간에는 보수적 swept envelope 또는 연속 충돌 검사를 사용하고, 미검증 구간을 기록한다. 변형된 시편과 케이블의 공간은 별도 모델로 검사한다.

## 14 데이터 구조와 개발 인터페이스

| 객체 | 필수 내용 |
|---|---|
| Material | 재료 ID, 물성값·범위·단위, 응력·변형률 정의, 온도·속도·방향, 출처, 신뢰 구분 |
| Specimen | 형상, 치수와 공차, 표점 길이와 그립 간 거리, 적층·배향, 시험부·물림부 구분 |
| TestPlan | 시험 종류, 목표, 제어 변수, 속도·주파수·파형, 종료 조건, 규격 프로파일 |
| Machine | 제조사·모델·형식·품목, 하중·속도·이동·공간, 조건부 제한, 근거 문서 |
| Component | 로드셀·그립·핀·어댑터의 정격, 정확도 범위, 질량, 연결 인터페이스, 실물 확인 상태 |
| Assembly | 구성품 순서, 좌표 변환, 초기 위치, 하중 경로, 간섭 제외 관계 |
| FixtureTemplate | 템플릿 ID·버전, 파라미터 정의, 생성기, 지원 계산·구조 모델 |
| CheckResult | 규칙 ID, 상태, 계산값·한계·여유, 단위, 적용 가정, 출처, 해결안 |
| DesignCandidate | 변경값, 부품 교체, 계산·CAD·해석 결과, 남은 UNKNOWN |
| ProjectRevision | 입력·도구·규칙 버전과 해시, 부모 버전, 변경 이유, 출력 경로 |

수치값에는 value 또는 lower/upper, unit, provenance, evidence_id를 붙인다. provenance는 manufacturer_document, measured, project_assumption, derived 중 하나다. null을 0으로 해석하지 않는다. 자료 미등록과 한계 없음은 서로 다른 값이다.

로드셀 측정 오차는 단일 “정확도 %”로 저장하지 않는다. 판독값 비율, 용량 비율, 절대 오차, 보증 하한, 방향, 교정일, 동적 적용성을 표현한다. 정적·동적 용량도 따로 저장한다.

프로그램 모듈:

- domain: 단위, 데이터 검증, 물성·장비·부품 모델.
- calculations: 인장·압축·굽힘·접힘 계산과 적용 범위 판정.
- rules: 규칙 실행, 상태 통합, 근거와 개선안 생성.
- design: 후보 생성, 고정 조건 보존, 후보 순위.
- cad_worker: CadQuery 작업 프로세스에서 템플릿 재생성·측정·내보내기. 기존 FCStd용 FreeCAD 어댑터는 선택적으로 연결한다.
- motion: 위치와 각도 이력, 간섭·공간 검증.
- analysis_adapter: 구조 해석 요청·결과 수신. 미실행 결과를 PASS로 바꾸지 않는다.
- report: 입력·변경·판정·근거를 묶은 HTML 및 JSON 보고서.
- api와 ui: 작업 생성, 진행 상태, 3D 표시, 비교, 내보내기.

주요 API 계약:

| 경로 | 입력 | 출력 |
|---|---|---|
| POST /projects | 이름과 시험 종류 | 프로젝트 ID와 초기 버전 |
| PUT /projects/{id}/input | 단위가 포함된 입력 전체 | 새 입력 버전, 유효성 결과 |
| POST /projects/{id}/evaluate | 입력 버전 | 작업 ID |
| POST /projects/{id}/candidates | 고정 조건과 탐색 범위 | 작업 ID |
| GET /jobs/{id} | 작업 ID | 대기·실행·완료·실패, 단계, 오류 원인 |
| GET /projects/{id}/results | 결과 버전 | 검증 항목, 후보, 형상 참조 |
| POST /projects/{id}/export | 선택 후보와 결과 버전 | 결과 묶음 경로 |

API가 임의 Python 파일을 받아 실행하지 않도록 한다. 등록된 템플릿 ID와 허용 파라미터만 입력받는다. 장시간 CAD 작업은 별도 프로세스에서 실행하고 시간 제한·취소·실패 복구를 구현한다.

## 15 기술 구성과 실행 방식

Python 계산 엔진과 FastAPI 로컬 서버, React·TypeScript 화면, Three.js 기반 3D 뷰어, SQLite 메타데이터, 파일 기반 프로젝트 폴더를 사용한다. CadQuery 작업자와 서버 Python 환경을 분리해 라이브러리 충돌을 줄인다. 선택적 FreeCAD와 PrusaSlicer는 검증된 실행 파일 경로를 지정한다. 제작 기능의 도구·데이터·인터페이스는 20~27절을 따른다.

Windows 실행 파일 또는 시작 스크립트 하나로 서버와 화면을 연다. 서버는 기본적으로 localhost에만 바인딩한다. 모든 정적 자산을 로컬에 포함하고 외부 CDN·클라우드·LLM 호출 없이 작동하도록 한다. Linux에서도 계산과 CAD 회귀 검증이 가능하도록 경로와 프로세스 실행을 추상화한다.

버전은 개발 착수 시 실제 설치·기동·CAD 재생성 테스트를 통과한 조합으로 고정한다. 최신 버전을 자동 추종하지 않는다. GPU는 필수 조건이 아니며, 초기 형상 규모는 일반 PC의 CPU로 처리 가능한 지그 조립으로 제한한다.

이번 제품은 장비 선정과 지그 설계 검토 도구다. Instron이나 Zwick 시험기를 직접 구동하지 않는다. 장비 제어가 필요해지면 해당 제조사의 허용 인터페이스와 제어·정지 조건을 별도 개발 범위로 정의한다. CAD가 무료여도 제조사의 시험 제어 소프트웨어 사용권이 없어지는 것은 아니다.

## 16 테스트 계획과 완료 기준

### 16.1 계산과 규칙 테스트

아래는 구현 시 필수 수용시험이다. 첨부 acceptance_tests.csv에서 ID별 입력 조건, 기대 결과, 검증 방식을 확인한다.

| 구분 | 핵심 테스트 |
|---|---|
| 수치 정답 | T1 하중, T2 신장·공간, C1 압축, C2 컴플라이언스, B1/B2 보 계산, F2 기구학 |
| 단위 | mm↔m, N↔kN, MPa↔Pa, %↔비율, deg↔rad, mm/s²↔m/s² |
| 한계 | 정격 직전·정격과 동일·정격 초과, 두께 최소·최대, 속도·공간 경계 |
| 물리 | 항복값만으로 파단 하중 산정 금지, 발포재 E로 대변형 외삽 금지, 적층재 등방성 치환 금지 |
| 데이터 | 단위 누락, NaN, 음수 치수, 범위 역전, 필수값 null, 실물 미확인 |
| 의도 보존 | 시편 치수와 접힘 반경을 자동으로 바꿔 통과시키지 않음 |
| 장비 | 본체·로드셀·그립의 최소 허용치, 정적/동적 정격 분리, 속도와 복귀 속도 구분 |
| 재현 | 같은 입력·버전에 동일 수치·판정, 변경 후 이전 결과 무효화 |

### 16.2 CAD와 화면 테스트

각 템플릿은 최소·대표·최대 치수와 실패 입력을 포함해 검증한다. 파라미터를 바꾼 뒤 실제 측정한 간격·두께가 목표와 맞아야 한다. 검사용 길이 허용오차 0.01 mm는 소프트웨어 형상 회귀 기준이며 가공 공차를 의미하지 않는다.

STEP 재불러오기 후 솔리드 수·기준 치수·체적을 비교한다. 부품이 빠진 내보내기, CAD 재생성 실패, 작업 취소, 중간 충돌, 표시용 메시와 CAD 버전 불일치를 검출한다. 화면에서 원안과 수정안의 변경 치수를 선택하면 해당 부품이 강조되어야 한다.

### 16.3 구조와 실물 검증

단순 지그는 독립 손계산이나 검증된 구조 해석과 비교한다. 접촉·미끄러짐·좌굴·복합재 손상처럼 입력 의존성이 큰 항목은 시험으로 보완한다. 실제 장착 시험에서는 치수, 초기 위치, 무시편 운동, 알려진 하중·변위, 지그 컴플라이언스 순서로 확인한다.

반복 접힘은 저속 궤적과 힘을 먼저 측정하고, 목표 속도에서 관성·발열·풀림·센서 신호를 확인한 뒤 단계적으로 반복 횟수를 늘린다. 짧은 무부하 반복 성공을 15만 회 수명 검증으로 표시하지 않는다.

### 16.4 완료 판정

- 계획된 모든 규칙·경계 수용시험이 통과하고, 설명 가능한 정답과 비교되어야 한다.
- 네 시험의 대표 CAD가 생성되며, 적합·부적합·판정 보류 사례가 모두 재현되어야 한다.
- 알려진 부적합 사례가 적합으로 나오는 오판이 없어야 한다.
- 모든 PASS에는 적용한 규칙·입력·근거·버전이 있어야 한다.
- 실제 제작용 출력은 필수 인터페이스와 구조 검증이 완료된 경우에만 허용한다. 미확인 상태에서도 검토용 CAD는 표시를 붙여 출력할 수 있다.
- 현장 실측이 없으면 “소프트웨어 기능 검증 완료”까지만 표시한다. “실물 시험 적합 확인”과 구분한다.

## 17 개발 단계와 산출물

| 단계 | 구현 내용 | 단계 종료 조건 |
|---|---|---|
| 0 데이터와 기준 정리 | 본 문서, 장비 프로파일, 시나리오, 검증 정책, CAD 인터페이스 | 제조사값·가정값 분리, 필수 누락 정의 |
| 1 공통 계산 | 단위·스키마·판정 엔진, 장비 하중·공간·정확도 검사 | 계산·경계·누락 입력 테스트 통과 |
| 2 굽힘 전체 흐름과 제작 | 입력 화면, B 템플릿, CAD 작업자, 변경 비교, 출력 방향·3MF·부품표·슬라이서 연결 | B1/B2 설계 흐름과 B1 제작 파일 재현 |
| 3 인장과 압축 | T/C 템플릿, 그립·센서·컴플라이언스 규칙 | T1~T3, C1~C3 재현 |
| 4 반복 접힘 | F 템플릿, 기구학, 운동·속도·관성·측정 검증 | F1~F3 재현, 미확인 동적 영역은 UNKNOWN 유지 |
| 5 공통 확장 | 챔버·온도, 공차·출력 레시피 검증, 해석 연동, 실행 패키지 | H1·P1~P6와 배포 환경 테스트 통과 |
| 6 현장 확인 | 실제 장비·부품 프로파일, 기존 성공·실패 사례 검증 | 현장 검증 기록과 적용 가능 범위 확정 |

개발 순서는 고정하지만 날짜와 인력 투입량은 실제 CAD·슬라이서 실행 환경 및 템플릿 난도를 확인한 뒤 산정한다. 상용 장비 구매와 실물 제작은 소프트웨어 개발 일정에서 별도 관리한다.

최종 프로그램 산출물은 소스 코드, 설치·실행 방법, 고정 의존성 목록, 네 시험의 파라메트릭 템플릿, 장비·제작 프로파일, 대표 사례, 자동 테스트, CAD 결과, 3MF·확인된 장비용 제작 파일, 부품표·조립도·검사표와 검토 보고서다. 계산 엔진은 UI 없이도 실행할 수 있어야 한다.

## 18 개발 인계 지시

개발자는 이 문서, equipment_profiles.json, scenario_inputs.json, acceptance_tests.csv와 제조 확장 파일 manufacturing_profiles.json, printing_scenarios.json, print_acceptance_tests.csv를 읽고 구현을 시작한다. 먼저 계산과 판정 엔진을 만든 다음 실제 CadQuery 재생성과 화면을 연결한다. 예제 데이터에 맞춰 결과를 하드코딩하지 않는다.

제조사 프로파일의 미확인 값을 임의 보충하지 않는다. 예제용 값을 쓰면 반드시 project_assumption으로 보관한다. 장비별 체결 치수의 원본 확인 전에는 제작용 연결부를 확정하지 않는다. 모든 수용시험을 실제로 실행하고, 실행하지 못한 시험은 사유와 함께 남긴다.

이번 기획 패키지의 verify_planning_examples.py는 문서에 등장하는 계산 예제를 검산하는 보조 코드다. 이것이 통과해도 제품 계산 엔진, CAD 생성, 간섭 검사, 구조 해석, 실물 검증이 완료된 것은 아니다. planning_calculation_results.json에는 이번에 실제 실행한 검산 결과만 담는다.

## 19 근거 자료

아래는 2026년 9월 28일 확인한 공식 제조사·프로젝트 자료다. 장비 운영은 실제 설치 모델의 매뉴얼과 교정 정보를 우선한다.

- [S1] ZwickRoell ProLine 제품 사양과 Z010 TH 각주: https://www.zwickroell.com/products/static-materials-testing-machines/universal-testing-machines-for-static-applications/proline/
- [S2] Instron 6800 제품군, 68TM-10 모델, CAD 사용 조건: https://www.instron.com/en/products/testing-systems/universal-testing-systems/6800-series/
- [S3] Instron ElectroPuls E1000 공식 데이터시트 V9, 특히 2쪽: https://www.instron.com/en/resources/literature/electropuls-e1000-testing-system/
- [S4] FreeCAD 공식 프로젝트와 Python API 안내: https://github.com/FreeCAD/FreeCAD
- [S5] FreeCAD 공식 라이선스 설명, 기업 사용과 모델 파일 권리: https://github.com/FreeCAD/FreeCAD-documentation/blob/main/wiki/License.md
- [S6] CadQuery 공식 프로젝트와 Apache 2.0 라이선스: https://github.com/CadQuery/cadquery
- [S7] ZwickRoell ISO 527-3 필름 인장시험, ASTM D882와의 차이: https://www.zwickroell.com/industries/plastics/thin-sheeting-and-plastic-films/tensile-properties-iso-527-3/
- [S8] ZwickRoell 압축시험과 소재별 시험법: https://www.zwickroell.com/industries/materials-testing/compression-test/
- [S9] ZwickRoell 압축·굽힘용 직접 변위 측정: https://www.zwickroell.com/accessories/extensometers/extensometers-for-compression-flexure-and-components-testing/
- [S10] ZwickRoell ISO 178 3점 굽힘시험: https://www.zwickroell.com/industries/plastics/thermoplastics-and-thermosetting-molding-materials/3-point-flexure-test-iso-178/
- [S11] Instron ElectroPuls 액세서리와 챔버의 E1000 제외 조건: https://instron.com/en/products/testing-systems/dynamic-and-fatigue-systems/electropuls-systems/electropuls-accessories/

제조사 자료는 장비의 특정 사실을 뒷받침한다. 시나리오 치수, 설계 계수 1.25, 센서 구성 목표, 형상 회귀 오차 0.01 mm, 지그 변형비 5%는 이 프로젝트의 개발 가정 또는 목표이며 제조사 보증값이 아니다.

## 20 3D 프린팅 제작까지 확장한 목표

최종 목표를 “수정 CAD 제공”에서 “실제로 제작하고 검사할 수 있는 지그 패키지 제공”으로 확장한다. 자연어로 변경 의도를 전달하고 파라미터 변경안을 확인한 다음, 시험 적합성·구조·출력 가능성을 검토하여 부품별 출력 파일과 조립 정보를 만든다.

전체 흐름은 시험 입력 → 장비 적합 검토 → 지그 후보 생성 → 제조 방식과 재료 선택 → 출력 방향을 포함한 구조 검토 → CAD 및 메시 검사 → 프린터 배치 → 슬라이싱 → 제작 파일 확인 → 출력·후가공·조립 → 치수와 지그 성능 확인이다. 제작 조건을 바꾸면 영향을 받는 검증을 다시 실행한다.

현재 이미지의 “자연어 변경, 코드 기반 CAD, 여러 방향 미리보기, 프린팅 파일 출력” 개념을 채택한다. 특정 게시물의 미확인 Skill이나 서비스에는 의존하지 않는다. 제품의 핵심은 자연어 입력 여부와 관계없이 같은 계산·CAD·제작 검증 경로를 이용하는 것이다.

### 20.1 자동화 도구 선택과 기존 기획의 변경

| 역할 | 선택 | 구체적 사용과 범위 |
|---|---|---|
| 기본 형상 생성 | CadQuery | Python과 파라미터로 BREP 솔리드·조립을 만들고 STEP, STL, 3MF를 내보낸다 |
| 대안 CAD 엔진 | build123d | 코드 기반 CAD와 3MF를 지원하는 후보. 초기에는 동시에 구현하지 않고 동일 템플릿 벤치마크가 필요한 경우 비교한다 |
| 확인과 기존 CAD 작업 | FreeCAD | STEP 확인, 기존 FCStd 자산 수정. CadQuery STEP을 열었다고 원래 파라미터 이력이 복구되지는 않는다 |
| 표시 | 기존 Three.js 뷰어 | 회전형 3D, 정면·후면·좌·우·위·아래 6뷰와 별도 등각뷰, 단면·치수·부품 강조 |
| 메시 검사 | Trimesh | 닫힘, 면 방향, 체적, 연결 성분, 크기와 좌표 검사. 자체 교차·최소 두께 등의 전체 판정을 이것 하나로 보장하지 않는다 |
| 3MF 패키지 | CadQuery 기본 출력, 필요 시 lib3mf | 단위·부품·배치를 보존. 제조 설정과 결과 해시는 별도 JSON에도 저장 |
| 슬라이싱 | PrusaSlicer CLI | 고정 버전과 검증된 프린터·재료·출력 설정으로 배치 슬라이싱, G-code와 추정량 생성 |
| 프린터별 확장 | SlicerAdapter 인터페이스 | 다른 슬라이서를 연결할 수 있도록 입력·결과 계약을 분리. 초기에는 PrusaSlicer 하나를 검증 |

이 선택은 이번 프로그램에 대한 구현 판단이다. CadQuery가 build123d보다 언제나 우수하다는 성능 비교 결과는 아니다. 초기 채택 이유는 Python 파라메트릭 모델, 조립, STEP와 3MF 출력 경로를 한 엔진으로 구성할 수 있기 때문이다. [S6, S12, S13]

CadQuery와 build123d는 Apache 2.0 기반이며 FreeCAD, 슬라이서, CAD 커널과 그 의존성의 배포 조건은 각각 관리한다. PrusaSlicer 공식 저장소는 AGPL 계열 라이선스를 사용한다. 별도 실행 방식으로 연동해도 배포 시 라이선스 검토가 사라지는 것은 아니다. 특정 회사의 유료 CAD 좌석을 필수로 만들지 않는 것이 설계 방향이다. [S4~S6, S14]

### 20.2 CAD 원본의 단일성

기본 원본은 “CadQuery 생성 Python + parameters.json + 템플릿·커널 버전”이다. STEP, STL, model.3mf, 표시용 GLB는 파생 결과다. 원본과 파생 결과마다 같은 설계 버전과 해시를 연결한다.

기존 FCStd 자산은 cad_backend=freecad인 별도 템플릿으로 지원할 수 있다. 한 부품을 CadQuery와 FreeCAD에서 동시에 독립 수정하지 않는다. FreeCAD에서 가져온 STEP를 바꾸면 기존 CadQuery 원본의 수정으로 간주하지 않고 별도 편집 자산으로 등록하거나 템플릿을 이식한다.

### 20.3 자연어 변경 기능

예: “지지 간격 128 mm와 시편 치수는 유지하고, 이 프린터에 들어가도록 베이스를 수정해 주세요.” 시스템은 고정 조건, 변경 가능한 베이스 길이·리브·분할 접합, 제조 제약을 구조화하고 후보별 차이를 보여준다.

LLM은 변경 의도와 파라미터 후보를 제안한다. 숫자 계산, 단위 검증, 부품 정격, 출력 조건 확인은 결정적 코드가 수행한다. 자연어에서 바로 임의 코드를 생성해 장비 제어 또는 프린터 실행으로 연결하지 않는다. 새로운 템플릿 생성은 개발 단계에서 CAD·규칙 테스트를 거쳐 등록한다.

기본 폼과 치수 편집은 오프라인으로 작동한다. 자연어 기능은 선택한 로컬 모델 또는 조직이 허용한 API를 연결한 경우에만 사용한다. LLM이 없다고 전체 프로그램이 중단되지 않는다. “작게 만들어 줘”처럼 고정 조건을 침범할 수 있는 표현은 무엇을 바꾸려는지 화면에서 확인한다.

## 21 무엇을 출력하고 무엇을 조립할 것인가

초기 제조 공정은 FFF/FDM 고분자 출력으로 정한다. 모든 부품을 플라스틱으로 만드는 것을 목표로 하지 않는다. 낮은 하중의 출력 구조물과 금속 접촉부·체결부를 조합하고, 지그별로 실제 하중 경로를 계산한다. 금속 인서트가 있다고 주변 플라스틱의 파손·크리프 검사가 면제되지는 않는다.

| 시험과 기존 사례 | 출력할 후보 부품 | 초기안의 금속·상용 부품 | 제작 후 확인 |
|---|---|---|---|
| T1 인장 설계 2.5 kN | 정렬 가이드, 교체 패드의 지지 형상, 센서 브래킷 | 주 하중 경로의 그립·어댑터·핀 | 물림부 미끄러짐, 하중축, 패드 손상 |
| T3 필름 설계 50 N | 그립 인서트·몸체 후보, 교체식 접촉 지지부 | 볼트·너트·필요한 하중 분산판 | 접촉압, 반복 조임, 물림부 파손과 변형 |
| C1 발포재 설계 625 N | 리브형 받침 몸체 후보, 위치 가이드 | 평탄한 압축 접촉판·체결부 | 압축 컴플라이언스, 접촉판 휨, 유지 하중 크리프 |
| C2 고강성 시편 설계 7.5 kN | 위치 가이드·센서 브래킷 중심 | 주 하중 경로·정밀 평판 | 지그 변형과 측정 오차. 고분자 구조화는 별도 검증 |
| B1 굽힘 설계 약 166.7 N | 베이스·좌우 지지 몸체 후보·위치 스토퍼 | 롤러·압자·볼트·하중 분산 부품 | 실제 지지 간격, 처짐, 접촉부 눌림, 반복성 |
| B2 굽힘 설계 약 333.3 N | 확대 베이스·리브·가이드 몸체 후보 | 롤러·압자·필요한 금속 보강판 | 휨·체결부·출력 크기와 방향 |
| F 반복 접힘 | 클램프 하우징·반경 인서트·센서 지지부 후보 | 회전축·베어링·마모 구동부·체결부 | 백래시, 반경 유지, 마모, 반복 수명 |
| H 챔버 | 온도별 검증 재료의 허용 부품만 | 온도에 적합한 연결부와 접촉부 | 온도·시간에 따른 치수·강성·크리프 |

첫 실물 목표는 B1 굽힘 지그의 출력 베이스와 지지 몸체에 금속 롤러·압자를 조립하는 것이다. “구조물은 전부 금속, 출력물은 장식만”으로 범위를 축소하지 않는다. 출력 구조물의 강도·강성·접촉부와 체결부를 검증해 실제 하중을 부담하게 하는 것이 개발 목표다. 위 하중은 시험 예제의 요구 하중이며 출력물의 허용하중 보증값이 아니다.

부품별 manufacturing_route는 printed, purchased, machined 중 하나로 저장한다. 출력 대상만 플레이트에 배치하고 금속 롤러나 볼트까지 함께 출력하지 않는다. 부품표에는 수량, 재료, 공정, 출력 방향, 후가공, 접합 방법, 교환 가능 여부를 포함한다.

## 22 프린터와 재료 및 출력 조건

### 22.1 기준 프린터와 초기 프로파일

개발 기준은 Prusa MK4S와 PrusaSlicer 조합으로 둔다. 공개 제작 공간은 X 250 × Y 210 × Z 220 mm이다. 실제 회사 프린터의 모델을 정하기 전에도 이 기준으로 배치와 출력 파일 파이프라인을 구현할 수 있다. [S18]

초기 제조 설정은 0.4 mm 노즐, 0.2 mm 적층 높이를 개발 시작값으로 둔다. 외벽 수, 채움률·패턴, 상하단 층 수, 온도, 속도, 냉각, 서포트는 재료·부품의 검증된 출력 레시피에서 가져온다. 온도 등의 실제 값을 재료 이름만 보고 생성하지 않는다. G-code는 실물 프린터·노즐·펌웨어·필라멘트 프로파일이 확인된 뒤에만 특정 장비용 결과로 확정한다.

프린터 모델·제작 공간·노즐 직경과 재질·온도 범위·챔버 유무·재료 호환성·좌표계·시작/종료 코드·펌웨어·슬라이서 버전을 독립 입력으로 등록한다. 제작 공간은 프린터 외형 치수가 아니라 실제 사용 가능한 베드와 높이를 사용한다. 브림, 서포트, 퍼지 영역, 클립 및 금지 구역을 포함해 판단한다.

### 22.2 시편 물성과 출력 지그 물성을 분리

시편의 응력·변형률 데이터로 시험 하중을 예측한다. 출력 지그의 데이터로 그 하중을 견디는지 판단한다. 두 재료 ID를 별도로 가진다. 시험할 시편이 CFRP라고 해서 출력 지그에도 CFRP 물성을 부여하지 않는다.

상온 첫 재료 후보는 PETG로 둔다. 제조사도 홀더·클램프·기계 부품에 사용하는 재료로 소개하지만, 이 사실만으로 해당 지그의 강도나 수명을 보증하지 않는다. 실제 브랜드·등급·색상·로트, 건조 상태, 프린터, 방향, 층 높이, 외벽, 채움, 온도·속도를 묶은 출력 재료 프로파일을 검증한다. [S19]

| 재료 후보 | 개발 용도 | 승인을 위해 추가할 근거 |
|---|---|---|
| PLA | 형상·조립 시제품 | 하중 지그나 고온 사용에는 별도 검증 |
| PETG | 상온의 첫 출력 구조물·가이드 후보 | 방향별 강도·강성, 압축·체결·시간 의존 거동 |
| PA 계열·단섬유 강화 소재 | 더 높은 강성 등 요구가 있을 때 비교 | 건조·흡습, 노즐 호환, 층간 성능, 가공·출력 반복성 |
| TPU 등 연질 재료 | 시편 보호 패드 후보 | 경도·압축·마찰·영구변형과 시험 결과 영향 |

단섬유 강화 필라멘트를 연속섬유 적층재와 동일하게 취급하지 않는다. 탄소섬유 충전 재료는 내마모 노즐 등 실제 장비 조건도 확인한다. 사출재의 물성표를 출력물 허용응력으로 직접 사용하지 않는다. [S17, S20]

### 22.3 방향과 채움 조건의 구조 검증

출력물은 등방성 완전 솔리드로 단정할 수 없다. 적층 방향과 하중 방향, 외벽과 내부 채움, 구멍 주변 하중 전달, 나사 체결 압력, 층간 파괴를 고려한다. 100% 채움도 사출재와 동일 물성 또는 무결함 솔리드라는 뜻이 아니다. 제조사 설계 가이드도 출력 방향별 이방성과 금속 핀 사용을 구분한다. [S17]

초기에는 확인된 출력 레시피에 한해 유효 강성·허용값을 사용한다. 검증된 등가 모델이 없는 낮은 채움 구조는 단순 체적비 × 탄성률로 계산하지 않는다. 필요 시 실제 내부 구조를 모델링하거나 동일 레시피의 지그·쿠폰 시험에서 보정한다. 채움률을 바꾸면 재료 프로파일 일치 여부부터 다시 확인한다.

후보 방향은 서로 다른 6개 면을 베드에 놓는 방향과 필요한 축 주위 회전으로 생성한다. 순위는 구조·측정 요구 충족 여부를 먼저 적용하고, 지지물 제거·기준면 품질·베드 접착·출력 시간·재료 소모를 뒤에서 비교한다. 도구가 제공하는 안정 자세나 체적 계산만으로 최적 구조 방향이라고 표시하지 않는다.

시간을 포함한 시험에서는 크리프·응력 완화·볼트 예압 손실·온도·습도에 따른 변화가 필요하다. 반복 접힘에서는 정적 강도만으로 15만 회 사용 적합을 부여하지 않는다. 시험 하중보다 조립 볼트의 예압이 큰 경우도 검사한다.

## 23 형상에서 실제 제작 파일까지

### 23.1 CAD와 출력용 메시 검사

1. CAD에서 실제 크기, 구멍 위치, 최소 살 두께, 필렛, 공구 접근과 조립 공간을 확인한다.
2. 메시를 생성할 때 현 오차와 각도 오차를 명시하고 버전과 함께 저장한다. CAD의 곡면을 거친 삼각형으로 바꿔 접촉 반경이 달라지지 않는지 확인한다.
3. Trimesh 등의 도구로 닫힌 메시, 면 방향, 연결된 몸체 수, 체적, 단위와 bounding box를 검사한다. watertight=True가 모든 자기 교차·출력 가능성·강도를 보증하지는 않는다. [S15]
4. 자동 메시 복구로 의도한 구멍이나 틈이 사라지지 않도록 원본과 복구 후의 치수·체적을 비교한다. 구조에 영향을 주는 수정은 CAD 원본으로 돌아가 처리한다.
5. 서포트 접근, 브리징, 공정별 최소 두께, 막힌 공간, 실제 압출 경로에서 누락되는 얇은 벽을 확인한다. “45도 이상이면 항상 출력 가능” 같은 공통 상수를 사용하지 않는다.

### 23.2 파일의 역할 구분

| 산출물 | 역할 | 포함하지 않는 보장 |
|---|---|---|
| 생성 코드와 parameters.json | 재생성 가능한 설계 원본 | 원본이 있어도 제작 적합은 별도 |
| STEP | CAD·해석·가공 교환 | CadQuery의 파라미터 이력을 복원하지 않음 |
| model.3mf | 단위, 부품, 모델의 출력용 전달 | 특정 슬라이서의 온도·노즐·제조 설정을 자동 포함한다고 가정하지 않음 |
| print_project.3mf | 슬라이서에서 저장한 모델·배치·설정 | 다른 슬라이서가 모든 확장 설정을 동일하게 해석한다는 보장 없음 |
| 부품별 STL | 호환용 메시 | 단위·부품 의미·제조 설정이 충분하지 않으므로 manifest 필요 |
| G-code 또는 지원 바이너리 형식 | 지정 프린터와 프로파일의 실행 파일 | 다른 프린터에서 재사용 가능한 범용 파일이 아님 |
| BOM·조립도·검사표 | 금속 부품, 후가공, 조립·확인 항목 | 금속 조립 없이 인쇄물만으로 완성된다고 간주하지 않음 |

CadQuery의 3MF 출력과 PrusaSlicer의 설정 포함 프로젝트는 별도 단계다. PrusaSlicer는 3MF 프로젝트에 모델과 설정을 저장할 수 있으며, CLI를 통한 자동화도 공식 지원한다. 채택 버전에서 지원하는 실제 옵션과 파일 형식을 테스트하여 고정한다. 프로젝트 저장 기능이 특정 CLI에서 지원되지 않으면 GUI 저장 단계를 명시하고 설정 JSON과 모델을 함께 제공한다. [S12, S14, S16]

### 23.3 슬라이싱 검증과 인계

슬라이서가 종료 코드 0을 반환하는 것만으로 완료하지 않는다. 적용된 프린터·재료·노즐·층 높이·외벽·채움·온도 설정을 결과에서 읽어 요청값과 비교한다. 3MF에 포함된 예전 설정이 우선 적용된 경우를 잡아낸다. 실제 경로의 범위, 금지 구역, 온도 한계, 빈 경로, 경고, 서포트, 부품 누락도 확인한다.

G-code 미리보기와 해석은 채택 펌웨어·형식에서 지원하는 명령을 기준으로 한다. 압출 좌표의 절대/상대 모드와 매크로가 있으므로 단순 문자열 검색만으로 실제 운동을 전부 검증했다고 표현하지 않는다. 지원하지 않는 형식은 UNKNOWN으로 남긴다.

시간·재료량은 슬라이서 추정과 실제 제작 기록을 구분한다. 비용은 출력물·서포트·폐기 재료, 기계 시간, 후가공·조립 노동, 구입 부품, 재출력률을 분리한다. 실제 단가가 없으면 숫자를 시장가격으로 표시하지 않는다.

제품 화면은 “설계 적합”, “출력 파일 준비”, “실물 검사 완료”를 별도로 표시한다. 출력 시작은 장비가 확인된 제작 작업에서 수행한다. 초기 버전은 파일 전달까지 구현하고, 네트워크 전송·원격 출력은 프린터 인터페이스가 확인된 후속 어댑터로 둔다.

## 24 제작 관련 추가 시나리오

### P1 베드에는 들어가지만 브림까지 포함하면 넘치는 경우

기준 프린터의 X 길이는 250 mm다. 부품 길이 244 mm, 양쪽 브림 각각 6 mm, 프로젝트의 가장자리 여유 각각 3 mm라면 필요한 X 길이는 262 mm로 초과한다. 지지 간격 등 고정 조건을 유지하며 베이스 외곽·귀·배치를 수정한다. 부품 220 × 120 × 40 mm의 같은 가정에서는 238 × 138 × 40 mm 공간이 필요하다.

길이를 줄일 수 없으면 방향 변경이나 분할 조립을 검토한다. 분할은 임의 절단이 아니라 하중 경로·체결·공차·강성을 포함한 새 설계 후보다. 베드에 맞추기 위해 시험 시편이나 지지 간격을 축소하지 않는다.

### P2 형상은 같아도 출력 방향을 바꾸면 부적합해지는 경우

로직 검증용 가상 출력 재료의 허용 인장응력을 면내 20 MPa, 적층방향 8 MPa로 두고, 지배 응력을 12 MPa라고 가정한다. 해당 단축 하중에서 허용값 대비 사용률은 각각 0.6과 1.5다. 같은 외형이어도 두 번째 방향은 부적합이다.

이 숫자는 PETG나 특정 제품의 실측 물성이 아니다. 실제 복합 응력에서는 해당 방향의 인장·압축·전단과 적합한 파손 기준이 필요하다. 응력값 12 MPa도 검증용 입력이며 이번 기획에서 수행한 유한요소 해석 결과가 아니다.

### P3 출력 구멍이 맞아도 끼워맞춤 편차가 큰 경우

가상 핀 지름 8.00 ±0.01 mm, 구멍 8.25 ±0.10 mm라면 최소·최대 지름 틈새는 0.14~0.36 mm다. 요구 범위 0.10~0.30 mm에서 최대 틈새가 초과한다. 후가공 또는 부시를 적용해 구멍이 8.20 ±0.05 mm로 확인되면 0.14~0.26 mm가 된다.

이 값은 프린터의 일반 정밀도가 아니다. 방향별 구멍 쿠폰과 실제 검사에서 공차를 확인한다. 열삽입 인서트의 인발·회전 저항은 별도로 확인하고, 큰 체결력이 작용하는 부위는 관통 볼트·와셔·금속 슬리브로 예압 경로를 설계한다.

### P4 출력 시간과 비용을 줄이면서 시험 조건을 유지하는 경우

슬라이서 추정값이라는 가정으로 본체 120 g, 서포트 30 g, 폐기 10 g을 사용한다. 가상 단가는 필라멘트 30,000원/kg, 평균 전력 0.15 kW, 출력 4시간, 전력 200원/kWh, 조립 0.5시간 ×25,000원/시간, 금속 부품 6,000원이다. 직접 비용 합은 23,420원이며 기계 감가·실패율·부가세는 제외한다.

자동 개선은 불필요한 서포트, 비구조 외곽, 조립 수를 줄이는 방향에서 시작한다. 채움률을 낮추거나 층 높이를 바꾸면 해당 레시피의 강도·강성 적합성을 다시 확인한다. 슬라이싱 전후 설정을 바꾸고도 예전 구조 검증을 유지하지 않는다.

### P5 챔버 온도에서 출력 재료의 근거가 없는 경우

사용 온도 80°C인데 등록된 검증 범위가 50°C까지인 가상 재료라면 사용 범위 밖으로 판정한다. 재료의 HDT 하나를 연속 사용 온도나 장시간 하중 허용값으로 대체하지 않는다. 온도·시간·습도에 맞는 근거가 없으면 해당 부품은 검증 보류하고 다른 재료·금속화 후보를 보여준다.

### P6 반복 접힘 부품의 마모와 교체 주기

목표는 기존 F2의 15만 회다. 출력 클램프와 반경 인서트의 정적 강도가 충분해도 마모, 체결 풀림, 백래시, 반경·강성 변화와 피로 데이터를 별도로 검사한다. 초기 반복 확인만으로 15만 회 보증을 표시하지 않는다. 교체형 인서트는 고유 부품 ID와 누적 횟수·검사·교체 기록을 가진다.

## 25 추가 데이터와 개발 계약

| 객체 | 추가 필드 |
|---|---|
| ManufacturingRoute | printed/purchased/machined, 공정과 부품별 수량, 하중 역할 |
| PrinterProfile | 모델·노즐·제작 공간·금지 구역·온도 한계·펌웨어·좌표계·실물 확인 |
| PrintedMaterialProfile | 시편 재료와 별도 ID, 브랜드·등급·로트, 출력 레시피, 방향별 물성·공차, 온도·시간·습도 범위 |
| PrintRecipe | 적층·외벽·채움·온도·속도·냉각·건조·서포트·노즐, 검증 범위와 근거 |
| OrientationCandidate | 부품→빌드 좌표 변환, 적층축, 기준면, 구조·서포트·표면 평가 |
| ManufacturingCompensation | 설계 공칭 치수와 출력 보정값, 구멍·수축 보정 근거, 적용 범위 |
| SliceJob | CAD·메시·프로파일 해시, 슬라이서 버전, 실제 적용 설정, 경고, 출력 파일·추정 시간·질량 |
| InspectionRecord | 지그 개체 ID, 출력 기록, 치수, 후가공, 체결 상태, 하중·변위 확인, 재검사 기한 |

추가 모듈은 manufacturing_rules, print_materials, mesh_validation, orientation_candidates, slicer_adapter, manufacturing_report, inspection_records다. 구조 해석용 모델에는 출력 좌표계와 재료 방향이 전달되어야 한다. 최종 조립 좌표와 베드 배치 좌표를 혼동하지 않는다.

추가 API는 POST /projects/{id}/manufacturing/evaluate, POST /projects/{id}/orientations, POST /projects/{id}/slice, GET /slice-jobs/{id}, POST /projects/{id}/manufacturing/export, POST /projects/{id}/inspections로 정의한다. 자연어 요청은 /change-proposals에 구조화된 제안으로 저장하고 승인된 파라미터 변경과 같은 검증 흐름을 사용한다.

입력 치수, 제조 보정 치수, 슬라이서 배율을 각각 저장한다. 구멍 치수 보정은 의도한 끼워맞춤을 실현하기 위한 제조 파라미터이며 시험의 목표 지지 간격 변경과 구분한다. 배율이 승인값과 다르면 출력 파일을 다시 검토한다.

보안·실행 경계는 기존 등록 템플릿 원칙을 유지한다. 모델이 제안한 코드나 외부 3MF의 시작 G-code를 무조건 실행하지 않고, 선택한 로컬 도구와 검증된 프로파일만 이용한다. 자연어 기능이 변경하는 대상은 형상과 제작 조건이며 시험기·프린터의 즉시 운전 명령과 분리한다.

## 26 추가 테스트와 제작 완료 조건

print_acceptance_tests.csv에 제조 과정의 필수 수용시험을 추가한다. 기존 시험 계산·장비 검사 53개도 유지한다. 기획에 필요한 수치 검산은 verify_printing_examples.py로 별도 실행하며 CAD·슬라이싱 테스트와 혼동하지 않는다.

검증 항목은 출력 방향별 허용값, 브림 포함 크기, 실제 베드 금지 구역, 단위, 메시 닫힘·부품 누락, 인서트 공차, 레시피 변경 후 판정 무효화, 슬라이서 설정 덮어쓰기, G-code 기종 일치, 지원하지 않는 명령, 프린터 미등록, 온도 범위, 반복 수명, 금속 부품 제외, 조립도·부품표, 출력물 실측이다.

소프트웨어 완료 조건: B1 수정 지그의 설계 원본·STEP·3MF·6뷰와 등각뷰·BOM·조립도·검사표가 연결되고, 확인된 프린터 프로파일로 슬라이싱한 파일의 실제 설정이 요청값과 일치해야 한다. 생성 성공과 구조·제작 검증 상태는 각각 남긴다. 6뷰는 원본 CAD에서 렌더링하며 생성형 이미지로 대체하지 않는다.

실물 완료 조건: 출력·후가공·금속부품 조립 후 지지 간격·평행도·접촉 반경·치수 공차·지그 컴플라이언스·관심 하중에서의 반복성을 확인한다. 검증된 기준 지그와 같은 시편을 시험해 하중·변위와 산포를 비교하고 허용 차이는 시험 목적과 측정 불확도에 맞춰 사전에 정한다.

개발은 기존 공통 엔진과 B1 전체 흐름에 제작 모듈을 먼저 연결하고, T/C/F 및 챔버에 확장한다. 검토용 출력, 시험 사용 적합, 실물 확인 완료를 따로 관리한다. 아직 프린터가 지정되지 않아도 CAD·메시·부품표와 프로파일 기반 사전 검증은 진행하고, 특정 기종 G-code와 실제 출력은 실물 장비 확인 후 연결한다.

## 27 제작 확장 근거 자료

- [S12] CadQuery 공식 입출력 문서, 파라메트릭 원본과 STEP·STL·3MF·glTF: https://cadquery.readthedocs.io/en/latest/importexport.html
- [S13] build123d 공식 프로젝트 및 입출력: https://github.com/gumyr/build123d 와 https://build123d.readthedocs.io/en/latest/import_export.html
- [S14] PrusaSlicer 공식 제품·CLI 안내와 소스: https://www.prusa3d.com/p/prusaslicer/ 와 https://github.com/prusa3d/PrusaSlicer
- [S15] Trimesh 공식 문서: https://trimesh.org/
- [S16] PrusaSlicer 3MF 프로젝트 저장: https://help.prusa3d.com/article/saving-projects-as-3mf_1773
- [S17] Markforged Composites Design Guide, 출력 이방성·방향·공차·금속 핀 설계: https://static.markforged.com/downloads/CompositesDesignGuide.pdf
- [S18] Prusa MK4S 공식 제품 사양: https://www.prusa3d.com/product/original-prusa-mk4s-3d-printer/
- [S19] Prusa PETG 재료 안내: https://help.prusa3d.com/article/petg_2059
- [S20] Prusa 충전 복합 필라멘트와 출력 조건: https://help.prusa3d.com/article/composite-materials-filled-with-carbon-kevlar-or-glass_167387
- [S21] 3MF Consortium lib3mf 공식 구현: https://github.com/3MFConsortium/lib3mf

제조사 가이드의 특정 프린터·재료에 적용되는 최소 치수나 강도 수치는 다른 장비의 공통 규칙으로 복사하지 않는다. P1~P6의 가상 물성·공차·가격·출력량과 기본 층 높이는 개발용 가정이며 실제 제작 보증값이 아니다.

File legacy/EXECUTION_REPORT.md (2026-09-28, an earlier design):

# 실제 실행 결과 — 2026-09-28

실행 결과: CAD·파일·출력 범위 검사 **72 PASS / 0 FAIL**, 계산·경계 조건 단위 테스트 **11 통과**, HTML 뷰어의 모의 Canvas 동작 검사 통과. 전체 제작 승인 상태는 **UNKNOWN**입니다. 거부해야 할 예제를 정상적으로 거부한 검사도 PASS에 포함됩니다.

## 실행한 내용

CadQuery 2.7.0 / OpenCascade로 지그 조립체를 생성하고, STEP을 다시 읽어 솔리드 수·체적을 검사했습니다. 출력 부품별 STL을 Trimesh 5.1.0으로 읽어 밀폐성·면 방향·체적·치수를 검사했습니다. 3MF의 단위와 메시 존재를 확인했습니다. 부품끼리의 교차 체적으로 초기 위치에서의 간섭을 검사했습니다.

실제 결과는 `outputs/results.json`과 `outputs/unit_tests.json`에 기록합니다. 독립 보 공식, 알려진 수치, 스케일링, 입력 보존, 비정상 입력, 시편 길이, 템플릿 선택, 출력 범위 경계, 기존 지그 거부 조건을 테스트했습니다. 3MF는 XML/메시 검사를 했으며 실제 슬라이서에서 재읽는 검사는 수행하지 않았습니다.

## 시나리오

가정: 직사각형 시편, E=2,000 MPa, 명목 굽힘강도=80 MPa, 목표 변형률=0.5%, 지지 간격/두께=16. 선형 소변형 보 근사이며 특정 시험 규격의 적합 판정이 아닙니다. 설계 하중 배수 1.25는 예제 입력으로서 출력물 강도 안전율을 대신하지 않습니다.

| 항목 | 초기 | 변경 |
|---|---:|---:|
| 시편 폭 × 두께 × 길이, mm | 10 × 4 × 80 | 10 × 8 × 200 |
| 요구 지지 간격, mm | 64 | 128 |
| 선택 베이스 길이, mm | 160 | 220 |
| 선택 지그 최대 간격, mm | 100 | 160 |
| 목표 변형률의 하중, N | 16.6667 | 33.3333 |
| 목표 변형률의 처짐, mm | 0.85333 | 1.70667 |
| 명목 굽힘강도 대응 하중, N | 133.3333 | 266.6667 |
| 위 강도 하중 × 1.25, N | 166.6667 | 333.3333 |
| 브림·여유 포함 베이스 점유 크기, mm | 178 × 98 × 12 | 238 × 98 × 12 |

사용 공식: L=16h, F=2bh²σ/(3L), δ=εL²/(6h), 목표 응력 σ=Eε. 목표 변형률 도달 하중과 명목 강도 도달 하중은 서로 다른 값입니다. 강도까지 선형성을 보장하지 않으므로 후자는 명목 응력식에 따른 하중 규모 추정입니다.

## 의도적으로 검출한 오류

1. 변경 시편은 간격 128 mm가 필요하지만 기존 지그는 최대 100 mm이므로 거부합니다. 시편 치수를 임의로 줄이지 않습니다.
2. 244 mm 베이스는 브림 8 mm + 외곽 여유 1 mm를 양쪽에 더하면 262 mm가 됩니다. 참조 프린터 X=250 mm를 넘어 거부합니다.
3. 220 mm 후보는 점유 238 mm로 범위에 들어오고 필요한 간격도 제공합니다.

프린터 판정은 각 부품을 평평하게 단독 배치할 때의 크기 검사입니다. 전체 부품 동시 배치, 실제 출력 가능 영역 마스크, 헤드 충돌, 출력 방향에 따른 강도, 서포트, 뒤틀림은 검증하지 않았습니다. 베이스를 220 mm로 골랐다는 이유만으로 구조 강도가 확보되지는 않습니다.

## 생산 판정: UNKNOWN

- 참조 Zwick Z010 TH 프레임 10 kN과 계산 하중만 비교했습니다. 실제 로드셀·그립·장착부·허용 모멘트·보정 상태는 미확인입니다. 장착부 형상도 현재 CAD에 없습니다.
- 금속 롤러/가압봉/볼트는 별도 부품입니다. 볼트 머리·축은 단순화했으며 나사산, 너트·와셔, 시험기 연결부 및 롤러 축방향 이탈 방지는 설계 완성 전입니다.
- 출력 재료, 방향별 강도, 크리프, 피로, 하중-변위 오차, 미끄럼, 접촉응력, 볼트 체결 및 FEA는 미검증입니다.
- 초기 위치의 교차 체적 검사는 움직임 전체 충돌·접촉·하중 전달 검증을 대신하지 않습니다.
- 출력 프린터 프로파일과 G-code는 없습니다. 실제 슬라이서 설치 및 실행, 실물 출력, 장착, 하중 시험은 수행하지 않았습니다.
- 기존 CAD 가져오기, 인장·압축·반복 굽힘, 입력 웹 UI는 후속 구현 대상입니다.
- 이미지 렌더링은 확인했습니다. HTML 뷰어는 로컬 JavaScript 모의 Canvas로 동작을 점검하며, 실제 브라우저 엔진에서의 시각 QA는 브라우저 설치 실패로 미실행입니다.

## 파일 구성

각 시나리오당 STEP 조립체 1개와 출력 부품 3개(베이스·좌지지대·우지지대)의 STL/3MF를 제공합니다. 총 STEP 2개, STL 6개, 3MF 6개입니다. CAD 스크린샷은 생성된 솔리드를 삼각 분할해 렌더링한 것으로 이미지 생성 모델을 사용하지 않았습니다.

기획 파일의 기존 53 + 26개 인수 검사는 그대로 NOT_RUN 상태입니다. 이 데모의 검사는 해당 제품 인수 검사 전체를 대체하지 않습니다. 전체 계획과 근거 출처는 `planning/fixture_plan.md`를 참고하세요.

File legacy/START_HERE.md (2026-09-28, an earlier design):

# 파라메트릭 실험 지그 — 실제 실행 데모

이 폴더 하나를 Codex 프로젝트로 전달하면 됩니다. 상세 기획, 실제 실행 코드, CAD, 검증 결과를 포함합니다.

## 결과부터 보기

- `outputs/cad_comparison.png`: 실제 CAD를 렌더링한 수정 전후 비교.
- `outputs/cad_viewer.html`: 별도 서버나 인터넷 없이 브라우저에서 열 수 있는 회전 뷰어. 단순 Canvas 메시 뷰어이며 CAD 편집기는 아닙니다.
- `outputs/modified/assembly.step`: 수정한 조립체, 단위 mm.
- `outputs/modified/printed_*.stl`, `printed_*.3mf`: 베이스와 좌우 지지대 각각의 출력용 형상. 각각 바닥 Z=0으로 이동했습니다.
- `outputs/results.json`: CAD 생성·재읽기·메시·간섭·출력 범위 검사 결과.
- `EXECUTION_REPORT.md`: 검증 범위와 미완료 항목.

## 실행

Python 3.12 환경에서 프로젝트 최상위 폴더를 작업 폴더로 사용합니다.

```bash
python -m venv .venv
```

Windows PowerShell:
```powershell
.venv\Scripts\python.exe -m pip install -r requirements.txt
.venv\Scripts\python.exe run_demo.py
.venv\Scripts\python.exe -m unittest discover -s tests -v
```

macOS / Linux:
```bash
.venv/bin/python -m pip install -r requirements.txt
.venv/bin/python run_demo.py
.venv/bin/python -m unittest discover -s tests -v
```

의존성 설치에는 인터넷이 필요합니다. 생성과 검사는 로컬 실행입니다. `run_demo.py`를 다시 실행하면 `outputs/`의 같은 이름 파일을 덮어씁니다. 결과를 보존하려면 먼저 복사하세요. 테스트한 OS는 Linux, Python 3.12.14입니다. 다른 OS에서의 설치는 아직 검증하지 않았습니다.

## 수정할 곳

- `inputs/bending.json`: 초기·변경 시편 물성/치수, 참조 장비, 프린터 출력 범위.
- `src/fixture.py`: 요구 간격·하중 계산, 베이스 선택, 파라메트릭 형상.
- `run_demo.py`: 생성, 검증, STEP/STL/3MF 내보내기, 이미지·뷰어 생성.
- `tests/test_rules.py`: 독립 보 공식 및 경계/거부 조건 회귀 테스트.
- `planning/fixture_plan.md`: 전체 제품 상세 기획 v1.1. 인장·압축·굽힘·반복 굽힘 확장 포함.
- `CODEX_TASK.md`: 후속 개발 작업 지시서.

## 범위

현재는 직사각형 시편의 저변형 3점 굽힘 데모입니다. 지지 간격 40–160 mm, 시편 폭 최대 16 mm, 목표 변형률 최대 1%를 적용합니다. 지지대·베이스 단면과 롤러는 고정 템플릿이며 임의 형상 입력을 자동 해석하지 않습니다. 베이스 160/220 mm 두 후보 중 조건을 만족하는 작은 후보를 선택합니다. 일반 최적화기는 아닙니다.

이 예제는 새로 작성한 CadQuery 템플릿입니다. 사용자의 기존 CAD 파일을 가져와 수정하는 기능은 아직 없습니다. 사진에서 CAD를 복원하거나 원본 설계를 복제한 것이 아닙니다.

3MF는 형상만 포함합니다. 슬라이싱, 출력 시간/재료량 산정, G-code 생성, 실제 출력은 미실행입니다. 금속 롤러·가압봉·볼트는 출력 대상으로 분류하지 않습니다. 하중 전달부 장착, 체결 완성, 롤러 이탈 방지 및 출력물 강도 검증 전에는 실험에 투입할 수 없습니다.

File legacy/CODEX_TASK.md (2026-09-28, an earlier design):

# Codex 후속 개발 작업 지시

당신은 이 저장소의 파라메트릭 실험 지그 프로그램을 이어서 개발합니다. 사용자는 소재 시편 치수/물성을 넣으면 시험기·프린터 제약을 검사하고 지그를 수정하여 제작 전 오류를 발견하는 프로그램을 원합니다. 실제 재제작을 줄이는 것이 목적입니다.

## 먼저 확인할 문서

1. `START_HERE.md`, `EXECUTION_REPORT.md`
2. `planning/fixture_plan.md` 전체 및 두 acceptance_tests CSV
3. 실행 소스, `inputs/bending.json`, `outputs/results.json`

기획 문서와 실제 구현을 구분하세요. 이 저장소의 구현 완료 범위는 3점 굽힘 예제 하나입니다. 기획의 79개 제품 인수 검사는 미실행이며 이번 데모 검사 통과로 완료 처리하면 안 됩니다.

## 첫 번째 작업 단위

- 가상환경에서 의존성을 설치하고 데모/단위 테스트를 재실행하여 기준 결과를 재현합니다.
- 숫자/단위/지원범위 검증을 입력 스키마로 분리합니다. 하드코딩된 템플릿 치수가 입력에 노출되는 문제를 정리합니다.
- 굽힘 기능에 실제 입력 폼을 연결합니다. 형상만 보는 현재 HTML을 입력→검증→미리보기→파일 다운로드 프로그램으로 발전시킵니다. 판정과 근거, UNKNOWN 이유를 표시합니다.
- 시편 정보, 프린터 정보, 시험기 부품 정격 중 하나라도 불명확하면 제작 승인으로 올리지 않습니다. 프레임 정격만으로 시스템 하중을 승인하지 않습니다.
- 웹을 쓴다면 로컬 Python 백엔드(CadQuery)와 프런트엔드를 분리하고, 생성 작업 격리·타임아웃·파일 이름 검증을 구현합니다. 자연어 입력은 검증된 구조화 파라미터까지만 변환하고, 임의 Python 코드 실행으로 연결하지 않습니다.

## 순차 확장

1. 실제 장비/로드셀/공구 장착 인터페이스 프로파일 및 단위 처리. Zwick Z010 TH는 참조 장비이며 실물 구성은 미확인입니다.
2. 현재 지그를 체결 가능한 설계로 보완: 너트·와셔·장착 어댑터, 롤러 보유 구조, 공차, 처짐·접촉·크리프/층간 강도 평가. 현재 333.33 N은 시편에서 계산한 설계 요구 하중이며 출력 지그의 검증 정격이 아닙니다.
3. 압축, 인장, 반복 굽힘 템플릿을 각각 별도 규칙으로 추가. 반복 굽힘을 정적 굽힘 모델로 처리하지 말고 기획의 Instron E1000 후보 조건을 확인합니다.
4. 실제 프린터·소재·노즐·레이어·출력 방향 프로파일을 입력받고 PrusaSlicer CLI 어댑터를 만듭니다. 3MF 형상과 슬라이서 프로젝트를 구분합니다. 베드 적합성만 통과한 상태에서 G-code를 생산용으로 표시하지 않습니다.
5. 기존 파라메트릭 CAD를 연결할 명시적 파라미터 매핑 API. STEP에는 원본 CAD의 설계 이력이 없을 수 있음을 처리합니다.
6. 최종적으로 검증된 출력 시험편 쿠폰 → 치수 확인 → 장착 확인 → 승인된 단계 하중 시험 → 결과 환류 흐름을 구현합니다.

매 작업 단위마다 실행 가능한 결과, 변경 이유, 실제 수행 테스트, 남은 미검증 항목을 보고하세요. 기존 코드와 결과를 바탕으로 이어가며 제품 전체를 완료했다고 표현하지 마세요. 테스트 실패를 통과로 바꾸려고 설계 요구나 안전 기준을 낮추지 마세요.

## 첫 회차 완료 조건

기존 데모 재현, 입력 검증 개선, 굽힘 입력 UI, 실제 파일 다운로드, 자동화된 대표 정상/실패 시나리오, 업데이트된 실행 가이드까지 완료합니다. 이후 위 순차 확장을 진행합니다. 실물 없는 상태에서도 소프트웨어 검증과 모형 제작 자료 작성은 계속하되, 실물 확인이 필요한 판정은 UNKNOWN으로 남깁니다.

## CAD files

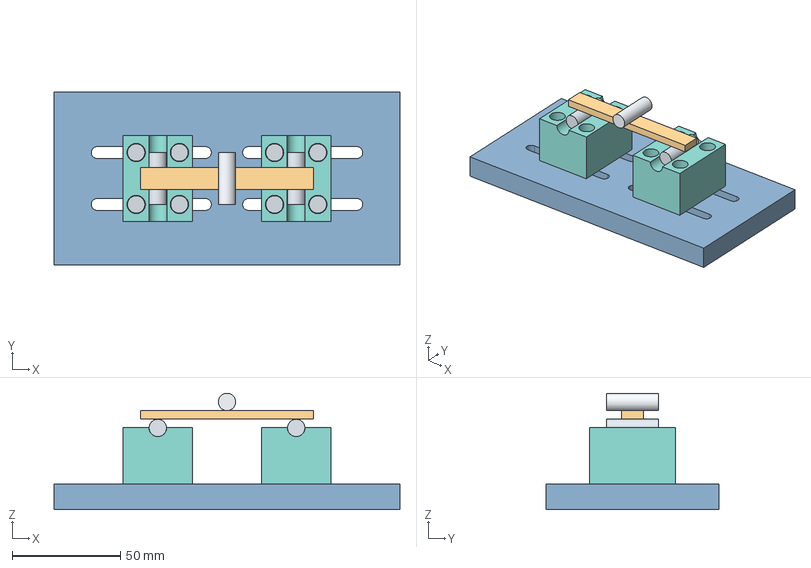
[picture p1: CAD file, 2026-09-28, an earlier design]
legacy/outputs/initial/assembly.step
160.0 x 80.0 x 53.9 mm
printed_base
metal_bolt_left_-10_-12
metal_bolt_left_-10_12
metal_bolt_left_10_-12
metal_bolt_left_10_12
printed_support_left
metal_roller_left
metal_bolt_right_-10_-12
metal_bolt_right_-10_12
metal_bolt_right_10_-12
metal_bolt_right_10_12
printed_support_right
metal_roller_right
specimen
metal_loading_nose

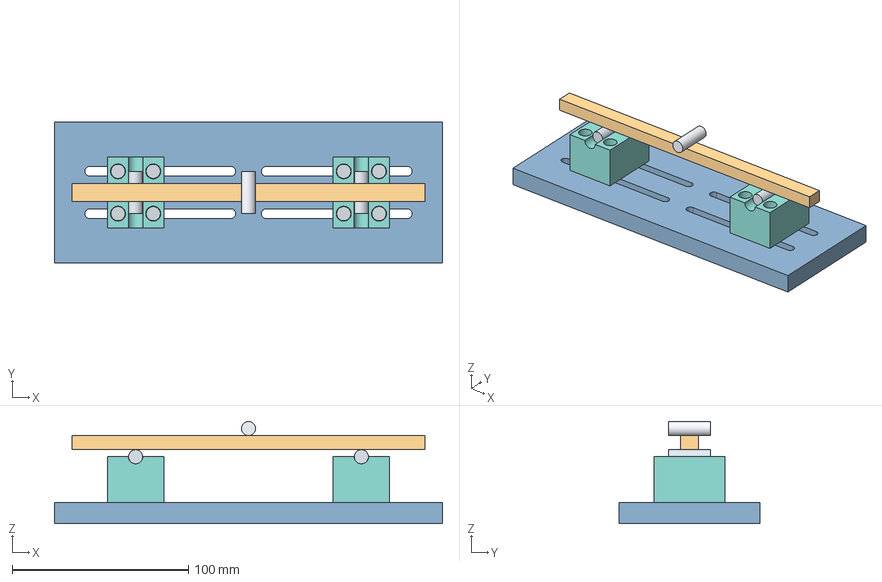
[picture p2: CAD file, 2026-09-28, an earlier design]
legacy/outputs/modified/assembly.step
220.0 x 80.0 x 57.9 mm
printed_base
metal_bolt_left_-10_-12
metal_bolt_left_-10_12
metal_bolt_left_10_-12
metal_bolt_left_10_12
printed_support_left
metal_roller_left
metal_bolt_right_-10_-12
metal_bolt_right_-10_12
metal_bolt_right_10_-12
metal_bolt_right_10_12
printed_support_right
metal_roller_right
specimen
metal_loading_nose

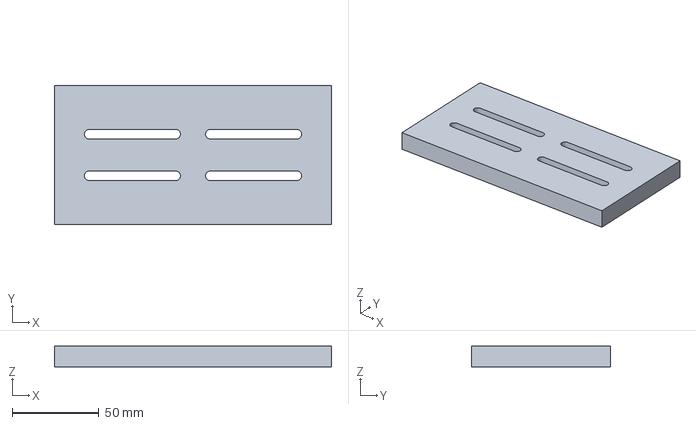
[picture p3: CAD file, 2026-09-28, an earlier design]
legacy/outputs/initial/printed_base.3mf
160.0 x 80.0 x 12.0 mm

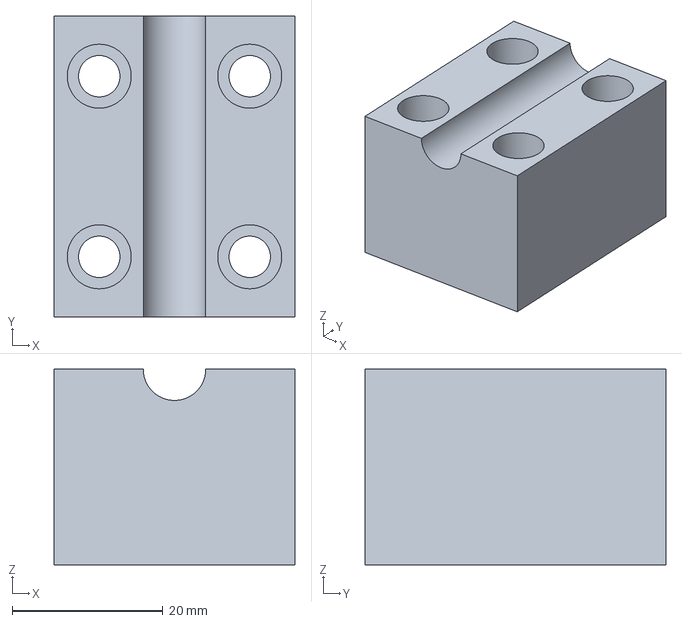
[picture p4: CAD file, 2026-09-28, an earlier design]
legacy/outputs/modified/printed_support_right.3mf
32.0 x 40.0 x 26.0 mm

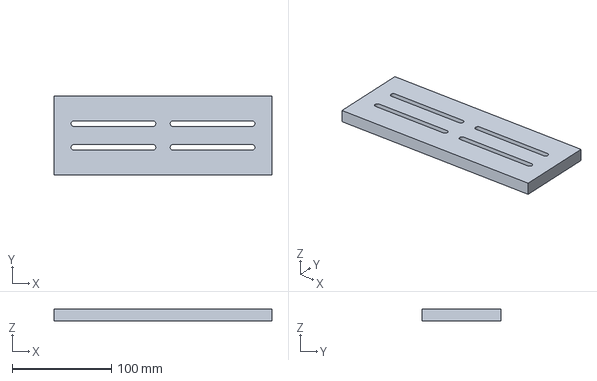
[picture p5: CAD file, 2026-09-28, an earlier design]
legacy/outputs/modified/printed_base.3mf
220.0 x 80.0 x 12.0 mm

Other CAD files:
legacy/outputs/initial/printed_support_right.3mf
legacy/outputs/initial/printed_support_left.3mf
legacy/outputs/modified/printed_support_left.3mf
legacy/outputs/initial/printed_base.stl
legacy/outputs/initial/printed_support_left.stl
legacy/outputs/initial/printed_support_right.stl
legacy/outputs/modified/printed_base.stl
legacy/outputs/modified/printed_support_left.stl
legacy/outputs/modified/printed_support_right.stl

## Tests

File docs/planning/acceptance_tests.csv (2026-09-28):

test_id | scope | input_or_action | expected_result | verification_method | execution_status
CAL-01 | T1 | 10×2 mm, 60~100 MPa | 1200~2000 N, 설계 2500 N | 수치 기준 | NOT_RUN_product_not_implemented
CAL-02 | T2 | 자유 길이 100 mm, 신장률 500% | 추가 신장 500 mm | 수치 기준 | NOT_RUN_product_not_implemented
CAL-03 | T2 | 높이 1450, 부속품 800, 자유 길이 100, 여유 100 | 가용 450 mm, 필요 500 mm → FAIL | 독립 공간 계산 | NOT_RUN_product_not_implemented
CAL-04 | T2 | 부속품 높이 650 mm로 변경 | 가용 600 mm, 공간 PASS; 종합은 미확인 항목 유지 | 독립 공간 계산 | NOT_RUN_product_not_implemented
CAL-05 | T3 | 단면 10×0.05 mm, 강도 80 MPa | 40 N, 설계 50 N | 수치 기준 | NOT_RUN_product_not_implemented
CAL-06 | C1 | 50×50×25 mm, 50%, 0.2 MPa | 500 N, 설계 625 N, 변위 12.5 mm | 수치 기준 | NOT_RUN_product_not_implemented
CAL-07 | C2 | E3000 MPa, A100 mm², L10 mm, ε0.02 | F6000 N, 시편 0.2 mm | 수치 기준 | NOT_RUN_product_not_implemented
CAL-08 | C2 | 지그 K20000 N/mm | 지그 0.3 mm, 겉보기 E1200 MPa | 직렬 스프링 독립식 | NOT_RUN_product_not_implemented
CAL-09 | C2 | 지그/시편 변형비 목표 5% | K지그 ≥600000 N/mm | 수치 기준 | NOT_RUN_product_not_implemented
CAL-10 | C3 | 단면400 mm², 응력40 MPa | 16000 N, 설계20000 N, 본체 FAIL | 수치 기준 | NOT_RUN_product_not_implemented
CAL-11 | B1 | b10 h4 L64 E2000 ε0.005 | 16.6666667 N, 0.8533333 mm | 보 공식 독립값 | NOT_RUN_product_not_implemented
CAL-12 | B2 | b10 h8 L128 E2000 ε0.005 | 33.3333333 N, 1.7066667 mm | 보 공식 독립값 | NOT_RUN_product_not_implemented
CAL-13 | F1 | h0.2, R안쪽2 mm | 중립면2.1 mm, ε0.0476190476 | 순수 굽힘 독립값 | NOT_RUN_product_not_implemented
CAL-14 | F2 | r12, 전체180°, 대칭 반각 | 총 stroke18.8495559 mm | 기구학 독립값 | NOT_RUN_product_not_implemented
CAL-15 | F2 | 2 Hz, A9.42477796 mm | vmax118.4352528 mm/s, amax1.4883013 m/s² | 조화 운동 기준값 | NOT_RUN_product_not_implemented
CAL-16 | F2 | 15만 회, 2 Hz | 20.8333333 h, 휴지 시간 제외 | 수치 기준 | NOT_RUN_product_not_implemented
CAL-17 | F3 | 센서2kN, 신호2N, S3 오차식 | 절대0.1 N, 상대5% → 목표1% FAIL | 제조사 식 비교 | NOT_RUN_product_not_implemented
UNT-01 | 공통 | N과 kN으로 같은 힘 입력 | 동일 결과 | 단위 변환 | NOT_RUN_product_not_implemented
UNT-02 | 공통 | MPa와 Pa, mm와 m의 동등 입력 | 동일 결과 | 단위 변환 | NOT_RUN_product_not_implemented
UNT-03 | 공통 | 500%와 무차원5 입력 | 동일 신장; 무단위500 거부 | 단위 변환 | NOT_RUN_product_not_implemented
UNT-04 | 공통 | 180 deg와 π rad 입력 | 동일 운동 | 단위 변환 | NOT_RUN_product_not_implemented
UNT-05 | F2 | 질량kg, 가속도mm/s² | 1000배 오차 없이 N 변환 | 단위 변환 | NOT_RUN_product_not_implemented
DAT-01 | 공통 | 필수 허용하중 null | UNKNOWN, PASS 금지 | 규칙 | NOT_RUN_product_not_implemented
DAT-02 | 공통 | 음수 두께, NaN, 역전 물성 범위 | 입력 거부 | 입력 검증 | NOT_RUN_product_not_implemented
DAT-03 | 공통 | 제조사값과 가상값 혼합 | 각 값의 provenance 유지 | 데이터 검증 | NOT_RUN_product_not_implemented
PHY-01 | T1 | 항복응력만 제공하고 파단시험 선택 | 최대 하중 UNKNOWN | 적용 범위 | NOT_RUN_product_not_implemented
PHY-02 | C1 | 발포재 E만 제공, 50% 압축 | 대변형 하중 UNKNOWN | 적용 범위 | NOT_RUN_product_not_implemented
PHY-03 | B3 | 적층재를 등방성 E 하나로 입력 | 적층 손상·정밀 하중 UNKNOWN | 적용 범위 | NOT_RUN_product_not_implemented
PHY-04 | T2 | 덤벨 표점길이만으로 큰 신장 계산 | 그립 이동량 확정 금지 | 적용 범위 | NOT_RUN_product_not_implemented
LIM-01 | 공통 | 설계하중이 확인된 정격보다 작음/같음/큼 | ≤는 해당 하중 검사 PASS, >는 FAIL; 별도 여유 경고 | 경계값 | NOT_RUN_product_not_implemented
LIM-02 | 공통 | 본체10kN, 센서1kN, 설계2.5kN | 센서 FAIL, 본체만으로 종합 PASS 금지 | 하중 경로 | NOT_RUN_product_not_implemented
LIM-03 | F2 | E1000 정적800N, 동적 한계1000N | 정적 용량710N 초과 FAIL | 방향과 모드 | NOT_RUN_product_not_implemented
LIM-04 | F2 | 스트로크만 만족, 동적 운전 영역 없음 | UNKNOWN | 동적 조건 | NOT_RUN_product_not_implemented
LIM-05 | T3 | 관심0.1N, 보증하한1N | 측정 범위 FAIL | 측정 품질 | NOT_RUN_product_not_implemented
LIM-06 | Zwick | 상부 부착공구 합21kg | TH형20kg 초과 FAIL | 질량 | NOT_RUN_product_not_implemented
LIM-07 | Zwick | 시험속도1200, 복귀속도1500 | 시험속도1000 초과 FAIL | 모드 구별 | NOT_RUN_product_not_implemented
INV-01 | C3 | 후보 탐색에서 시편 단면 고정 | 단면 자동 축소 금지 | 불변조건 | NOT_RUN_product_not_implemented
INV-02 | F1 | 반경2mm 고정 | 반경5mm를 같은 시험 성공으로 제시 금지 | 불변조건 | NOT_RUN_product_not_implemented
INV-03 | B2 | 시편길이80, 필요한 span128 | FAIL, 지그 확대만으로 통과 금지 | 불변조건 | NOT_RUN_product_not_implemented
CAD-01 | 네 템플릿 | 파라미터 최소·대표·최대 | 유효 솔리드, 측정 치수 오차≤0.01mm | 실제 CadQuery 또는 등록된 CAD 엔진 실행 | NOT_RUN_product_not_implemented
CAD-02 | 네 템플릿 | STEP 출력 후 다시 열기 | 솔리드 수·기준 치수·체적 보존 | 왕복 검사 | NOT_RUN_product_not_implemented
CAD-03 | 공통 | 재생성 실패·시간 초과 | 작업 실패 표시, 이전 정상 원본 보존 | 장애 주입 | NOT_RUN_product_not_implemented
CAD-04 | F2/H1 | 시작·끝은 정상, 중간 위치 충돌 | 충돌 FAIL 및 위치 표시 | 경로 검사 | NOT_RUN_product_not_implemented
CAD-05 | 공통 | 표시 메시 버전과 CAD 버전 다름 | 결과 사용 중지, 재생성 요청 | 버전 검사 | NOT_RUN_product_not_implemented
CAD-06 | 공통 | 스터드 직경만 있고 핀 치수 없음 | 제작용 연결부 출력 보류, 검토용 표시 | 근거 검사 | NOT_RUN_product_not_implemented
UI-01 | 공통 | 결과 후 입력값 변경 | 이전 결과 만료 표시 | 전체 흐름 | NOT_RUN_product_not_implemented
UI-02 | 공통 | 문제 항목 클릭 | 해당 실제 3D 부품 강조 | 전체 흐름 | NOT_RUN_product_not_implemented
REP-01 | 공통 | 동일 입력·버전으로 재실행 | 동일 계산과 판정, 파일 타임스탬프 차이는 허용 | 재현성 | NOT_RUN_product_not_implemented
REP-02 | 공통 | 결과 내보내기 | 입력·출처·규칙·CAD 버전·미확인 항목 포함 | 내용 검사 | NOT_RUN_product_not_implemented
INT-01 | 공통 | 네트워크 없이 프로그램 실행 | 계산·CAD·화면 작동, CDN 필요 없음 | 패키지 시험 | NOT_RUN_product_not_implemented
INT-02 | 공통 | 계산 PASS, 구조 미실행 | 종합 적합 금지; 구조 UNKNOWN 유지 | 상태 통합 | NOT_RUN_product_not_implemented
REAL-01 | 정적 | 실제 그립·센서 장착 | 치수·하중축·공간·측정 근거 확보 | 현장 실측 | NOT_RUN_product_not_implemented
REAL-02 | 반복 접힘 | 저속→목표속도→반복 단계 | 관성·발열·백래시·풀림·신호와 수명 기록 | 현장 실측 | NOT_RUN_product_not_implemented

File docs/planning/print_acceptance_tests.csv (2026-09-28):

test_id | scope | input_or_action | expected_result | verification_method | execution_status
PRT-01 | P1 | 244+브림12+여유6 mm | 262>250 → 배치 FAIL | 수치와 배치 | NOT_RUN_product_not_implemented
PRT-02 | P1 | 220×120×40 mm+같은 여유 | 238×138×40 상자 검사 PASS, 강도 별도 | 수치와 배치 | NOT_RUN_product_not_implemented
PRT-03 | P2 | σ12, 허용XY20/Z8 MPa | 사용률0.6/1.5, Z 방향 FAIL | 방향 규칙 | NOT_RUN_product_not_implemented
PRT-04 | P3 | 핀8±0.01, 구멍8.25±0.10 | 틈새0.14~0.36, 요구최대0.30 초과 | 공차 | NOT_RUN_product_not_implemented
PRT-05 | P3 | 후가공 구멍8.20±0.05 | 틈새0.14~0.26, 조건 내 | 공차 | NOT_RUN_product_not_implemented
PRT-06 | P4 | 가상 단가와 질량·시간 | 직접 비용23420원, 추정·제외항목 명시 | 비용 | NOT_RUN_product_not_implemented
PRT-07 | P5 | 사용80°C, 검증범위≤50°C | 범위 FAIL, 해당 온도 구조 UNKNOWN | 재료 범위 | NOT_RUN_product_not_implemented
PRT-08 | P6 | 정적 자료만, 목표15만 회 | 피로·마모 UNKNOWN | 수명 | NOT_RUN_product_not_implemented
PRT-09 | 공통 | 열린 메시 또는 뒤집힌 면 | 출력 검증 실패, 원인 표시 | 메시 | NOT_RUN_product_not_implemented
PRT-10 | 공통 | watertight지만 자체교차·얇은벽 존재 | 닫힘만으로 출력 적합 부여 금지 | 메시와 실제 경로 | NOT_RUN_product_not_implemented
PRT-11 | 공통 | 모델 mm, STL을 inch로 해석 | 25.4배 치수 오류 검출 | 단위 | NOT_RUN_product_not_implemented
PRT-12 | 공통 | 단위 3MF 재불러오기 | 원본 치수·부품·배치 보존 | 파일 왕복 | NOT_RUN_product_not_implemented
PRT-13 | 공통 | 외벽·채움·방향 변경 | 이전 구조·레시피 검증 만료 | 변경 추적 | NOT_RUN_product_not_implemented
PRT-14 | 공통 | 3MF 내부 프로파일과 요청 프로파일 다름 | 실제 적용 설정 비교 후 불일치 검출 | 슬라이서 통합 | NOT_RUN_product_not_implemented
PRT-15 | 공통 | 출력 성공코드, 빈 G-code 또는 부품누락 | 제작 파일 실패 | 슬라이서 통합 | NOT_RUN_product_not_implemented
PRT-16 | 공통 | 미등록 프린터 또는 펌웨어 | 특정 장비용 G-code 적합 확정 금지 | 장비 | NOT_RUN_product_not_implemented
PRT-17 | 공통 | G-code 온도·경로가 장비 한계 초과 | FAIL | 제작 파일 | NOT_RUN_product_not_implemented
PRT-18 | 공통 | 미지원 명령·매크로·바이너리 형식 | UNKNOWN, 검증 완료 표시 금지 | 제작 파일 | NOT_RUN_product_not_implemented
PRT-19 | 공통 | 금속 롤러·볼트가 조립에 포함 | 출력대상에서 제외, BOM에 유지 | 공정 분리 | NOT_RUN_product_not_implemented
PRT-20 | 공통 | 자연어로 작게 만들어줘 | 고정 시편·반경·지지간격 유지 | 의도 보존 | NOT_RUN_product_not_implemented
PRT-21 | 공통 | BOM·출력물·CAD 개정 불일치 | 조립 패키지 무효 | 추적 | NOT_RUN_product_not_implemented
PRT-22 | 공통 | 메시 자동 복구 후 구멍 사라짐 | 원본 차이 검출, 제작 확정 금지 | 복구 검증 | NOT_RUN_product_not_implemented
PRT-23 | 공통 | 6뷰·등각뷰 생성 | 같은 CAD 개정의 실형상, 치수 및 방향 일치 | 시각 검사 | NOT_RUN_product_not_implemented
PRT-24 | 공통 | 외관은 정상이나 기준 치수·강성 실패 | 실물 검사 FAIL, 사용 적합과 구분 | 현장 실측 | NOT_RUN_product_not_implemented
PRT-25 | 공통 | 채움률만으로 사출재 E 보정 | 검증 모델 없으면 구조 UNKNOWN | 재료 모델 | NOT_RUN_product_not_implemented
PRT-26 | 공통 | 브림은 안 넘지만 서포트·금지구역과 겹침 | 배치 FAIL | 배치 | NOT_RUN_product_not_implemented

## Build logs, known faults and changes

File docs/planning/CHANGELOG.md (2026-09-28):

# 변경 기록

## 1.1 2026년 9월 28일
- 수정 지그의 3D 프린팅 제작·후가공·조립·실물 검사까지 범위 확장.
- CadQuery를 기본 CAD 엔진으로 채택. FreeCAD는 확인·편집 및 기존 FCStd 어댑터로 유지.
- 자연어 수정 제안, 6뷰·등각뷰, Trimesh 검사, 3MF 구분, PrusaSlicer 연동 정의.
- Prusa MK4S를 개발 기준 프로파일로 등록. 실물 프린터·레시피는 미확인 상태 유지.
- 시편 물성과 출력 지그 물성을 분리. 방향·채움·외벽·크리프·피로·체결 검증 추가.
- 제작 시나리오 6개와 수용시험 26개 추가. 기존 13개 시나리오·53개 수용시험 유지.
- 변경 파일은 기존 기획서와 개발 인계 패키지의 개정본으로 저장.

## 1.0
- 장비 사양, 네 시험의 시나리오, 계산·CAD·검증·화면 기획.

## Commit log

2026-09-28 Build executable fixture design app with CAD verification, engineering examples and CI reports
    [acceptance_tests.csv, assembly.step, print_acceptance_tests.csv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]
2026-09-28 Fix browser report assertion and verify rejected cases export no CAD
2026-09-28 Generate Korean PDF summary automatically from verified CI CAD outputs
2026-09-28 Verify bending fixture slot travel and contact interfaces
2026-09-29 Add Gmsh CalculiX structural screening of printed bend support
2026-09-29 Support directional print elasticity and correct result node matching
2026-09-29 Generate evidence-led design verification PDF in CI
2026-09-29 Read CAD model parameters from source and rebuild fixture parts
2026-09-29 Add interactive FreeCAD face picking with probed dimension suggestions
2026-09-29 Keep native editor results in sync with selected CAD and assert picked dimension flow
